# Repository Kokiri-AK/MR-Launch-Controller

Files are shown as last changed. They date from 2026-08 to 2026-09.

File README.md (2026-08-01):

# MR-Launch-Controller
Model Rocket Launch Controller Schematic

Original Schematic: Ryan Wilkus

Forked by Jonathan M

Circuit is originally based on a great paper from 2009 by J.R. Brohm discussing model rocket igniter continuity testing [Paper](https://www.rocketshoppe.com/info/Igniter_Continuity_Tests.pdf). 

The paper proposed using a transistor circuit to decrease the continuity check current of the igniter. This circuit is an expanded realization of that suggestion.

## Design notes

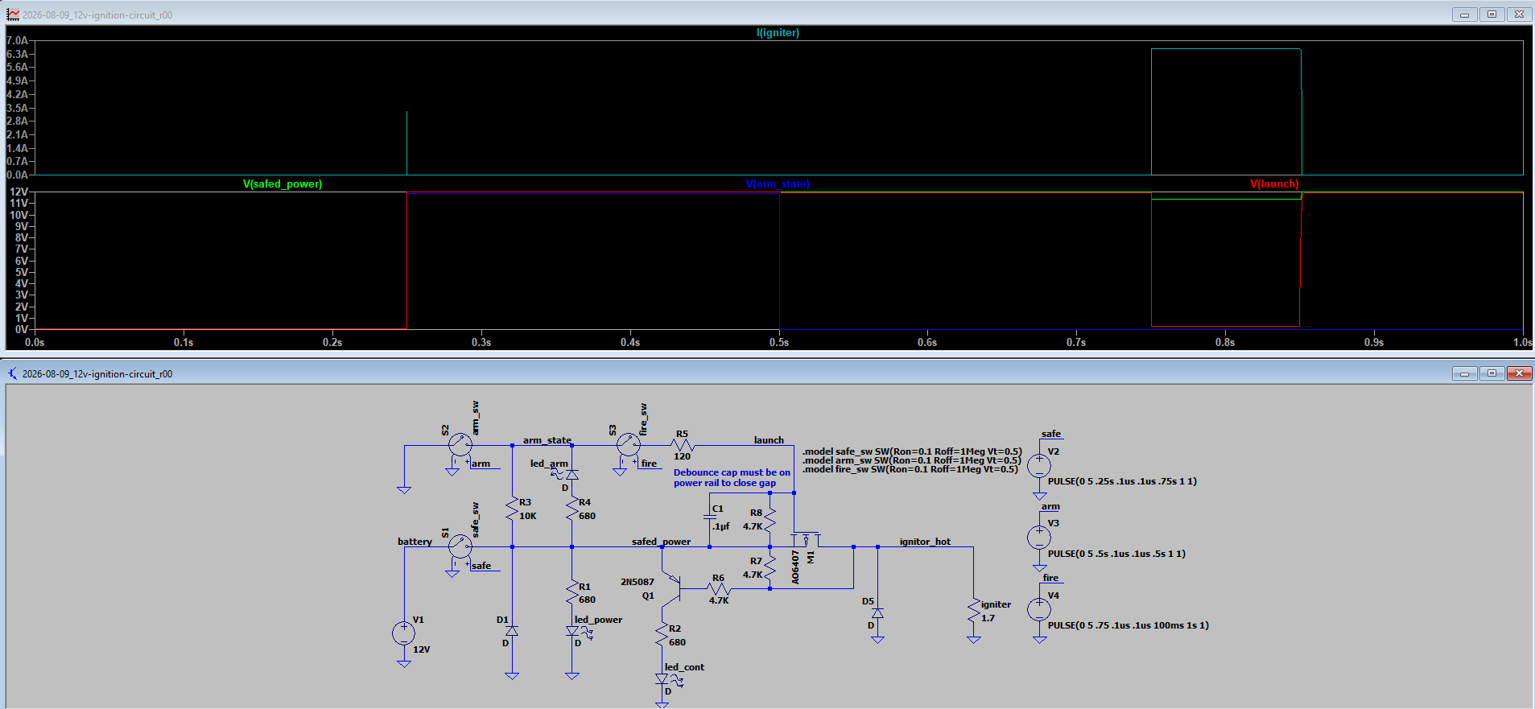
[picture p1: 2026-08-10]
5_Photos/12v_simulation.png

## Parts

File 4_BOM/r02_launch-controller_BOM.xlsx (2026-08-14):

Index | Manufacturer Part Number | Manufacturer Name | Description | Attrition % | Requested Quantity 1 | Pack Quantity 1 | Pack Type 1 | Digi-Key Part Number 1 | Unit Price 1 | Extended Price 1 | Minimum Order Quantity 1 | Customer Reference | Reference Designator | Part Status | RoHS Status | Original Part numbers
1 | 1729128 | Phoenix Contact | TERM BLK 2P SIDE ENT 5.08MM PCB |  | 1 | 1 | Bulk | 277-1247-ND | 0.95 | 0.95 | 1 | J1 |  | Active | ROHS3 Compliant | 1729128
2 | D6R40 F2 LFS | C&K | SWITCH PUSH SPST-NO 0.1A 32V |  | 1 | 1 | Tray | 401-1992-ND | 1.08000 | $1.08 | 1 | SW2 |  | Active | ROHS3 Compliant | 401-1992-ND
3 | BU-34 | Mueller Electric Co | GATOR CLIP STEEL NON-INSUL 5A |  | 2 | 2 | Bulk | 314-1017-ND | 0.54000 | $1.08 | 1 |  |  | Active | RoHS Compliant | 314-1017-ND
4 | C566D-RFE-CV0X0BB1 | CreeLED, Inc. | LED RED DIFFUSED 5MM OVAL T/H |  | 1 | 1 | Bulk | C566D-RFE-CV0X0BB1-ND | 0.18000 | $0.18 | 1 | D5 |  | Active | RoHS Compliant | C566D-RFE-CV0X0BB1-ND
5 | C5SMF-GJE-CX14Q7T2 | CreeLED, Inc. | LED GREEN CLEAR 5MM OVAL T/H |  | 1 | 1 | Cut Tape (CT) | C5SMF-GJE-CX14Q7T2CT-ND | 0.30000 | $0.30 | 1 | D3, D4 |  | Active | RoHS Compliant | C5SMF-GJE-CX14Q7T2CT-ND
7 | 2N3906 | Diotec Semiconductor | TRANS PNP 40V 0.2A TO-92 |  | 1 | 1 | Bulk | 4878-2N3906CT-ND | 0.77000 | 0.14 | 1 | Q1 |  | Active | ROHS3 Compliant | 4878-2N3906CT-ND
8 | ANT11SF1CQE | CIT Relay and Switch | SWITCH TOGGLE SPDT 5A 120V |  | 1 | 1 | Bulk | 2449-ANT11SF1CQE-ND | 1.26000 | $1.26 | 1 | SW1 |  | Active | RoHS Compliant | 2449-ANT11SF1CQE-ND
9 | P6KE18A | YAGEO | TVS DIODE 15.3VWM 25.2V DO204AC |  | 2 | 2 | Box | P6KE18ALFCT-ND | 0.38000 | $0.76 | 1 | D1, D2 |  | Active | ROHS3 Compliant | P6KE18ALFCT-ND
10 | 0ZRS1000FF1A | Bel Fuse Inc. | PTC RESET FUSE 32V 10A RADIAL |  | 1 | 1 | Cut Tape (CT) | 5923-0ZRS1000FF1A-ND | 2.24 | 2.24 | 1 | PTC1 |  | Active | ROHS3 Compliant | 5923-0ZRS1000FF1A-ND
11 | CF14JT300R | Stackpole Electronics Inc | RES 300 OHM 5% 1/4W AXIAL |  | 3 | 3 | Cut Tape (CT) | CF14JT300RCT-ND | 0.10000 | $0.30 | 1 | R1, R4, R7 |  | Active | ROHS3 Compliant | CF14JT300RCT-ND
12 | CF14JT4K70 | Stackpole Electronics Inc | RES 4.7K OHM 5% 1/4W AXIAL |  | 3 | 3 | Cut Tape (CT) | CF14JT4K70CT-ND | 0.10000 | $0.30 | 1 | R2, R3, R6 |  | Active | ROHS3 Compliant | CF14JT4K70CT-ND
13 | AOD413A | Alpha & Omega Semiconductor Inc. | MOSFET P-CH 40V 12A TO252 |  | 1 | 1 | Cut Tape (CT) | 785-1218-1-ND | 1.12 | 1.12 | 1 | Q2 |  | Active |  | AOD413A
14 | CC0603ZRY5V9BB104 | YAGEO | CAP CER 0.1UF 50V Y5V 0603 |  | 1 | 1 | Cut Tape (CT) | 311-1343-1-ND | 0.1 | 0.1 | 1 | C1 |  | Active |  | CC0603ZRY5V9BB104
15 | CF14JT10K0 | Stackpole Electronics Inc | RES 10K OHM 5% 1/4W AXIAL |  | 1 | 1 | Cut Tape (CT) | CF14JT10K0TR-ND | 0.1 | 0.1 | 1 | R8 |  | Active |  | CF14JT10K0
16 | CF14JT62R0 | Stackpole Electronics Inc | RES 62 OHM 5% 1/4W AXIAL |  | 1 | 1 | Cut Tape (CT) | CF14JT62R0CT-ND | 0.1 | 0.1 | 1 | R9 |  | Active |  | CF14JT62R0

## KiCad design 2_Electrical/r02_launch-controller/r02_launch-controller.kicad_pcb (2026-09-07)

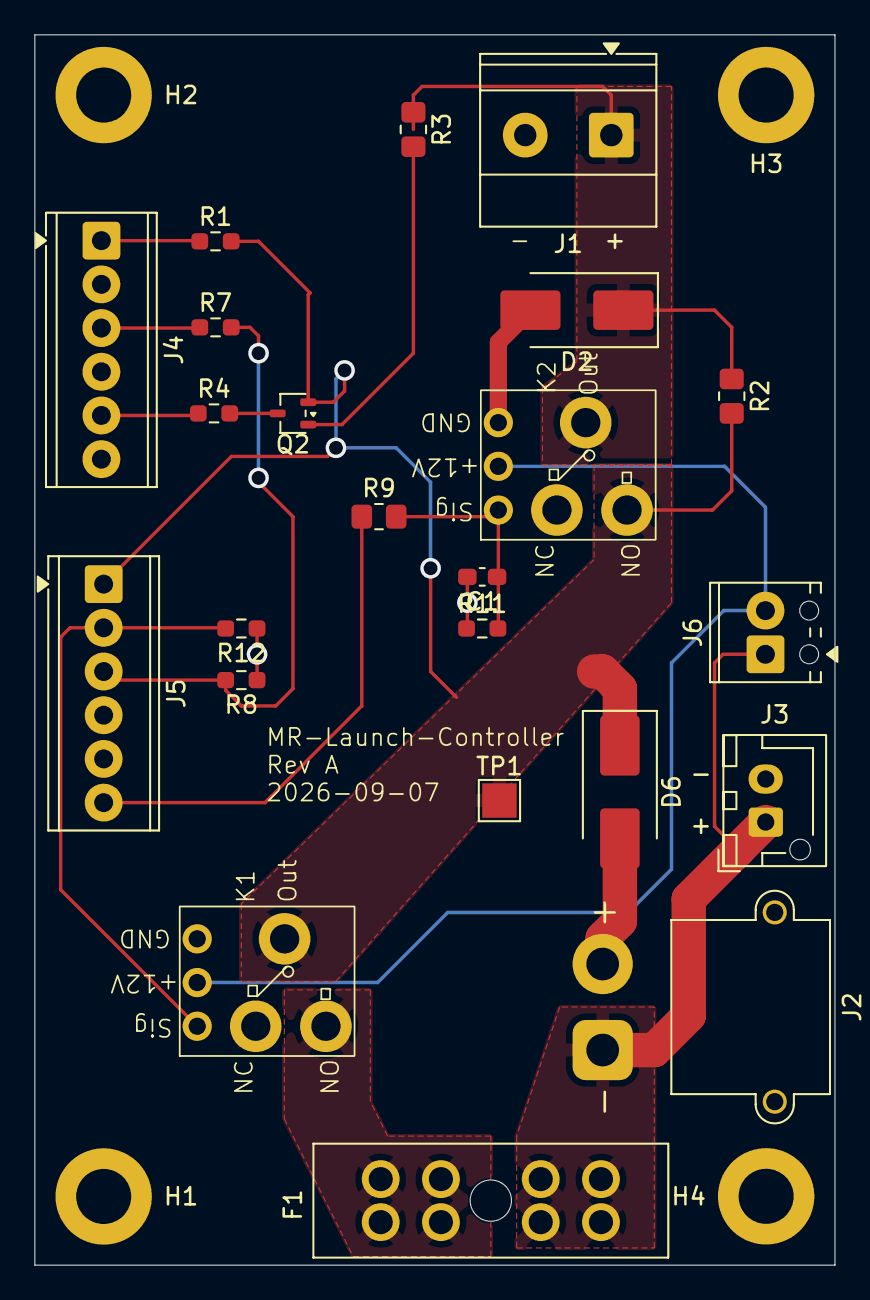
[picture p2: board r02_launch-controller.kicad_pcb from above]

Board: 2 copper layers, 46.5 x 71.5 mm, 27 parts (0 on the bottom side), 15 nets.

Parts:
C1: .1uf; C_0603_1608Metric_Pad1.08x0.95mm_HandSolder
D2, D6: SM6T18A; D_SMB_Handsoldering
F1: 178.6165.0001; FuseHolder_Blade_ATO_Littelfuse_FLR_178.6165
H1, H2, H3, H4: MountingHole; MountingHole_3.2mm_M3_DIN965_Pad
J1: 1729128; TerminalBlock_Phoenix_MKDS-1,5-2_1x02_P5.00mm_Horizontal
J2: XT30PW-M; AMASS_XT30PW-M_1x02_P2.50mm_Horizontal
J3: B2B-XH-AM; JST_XH_B2B-XH-AM_1x02_P2.50mm_Vertical
J4, J5: 1725698; TerminalBlock_Phoenix_MPT-0,5-6-2.54_1x06_P2.54mm_Horizontal
J6: Screw_Terminal_01x02; TerminalBlock_Phoenix_MPT-0,5-2-2.54_1x02_P2.54mm_Horizontal
K1, K2: 12V-relay
Q2: BC807W; SOT-323_SC-70
R1, R4, R7: 300; R_0603_1608Metric_Pad0.98x0.95mm_HandSolder
R2, R3: 4.7K; R_0805_2012Metric_Pad1.20x1.40mm_HandSolder
R8, R11, R12: 10K; R_0603_1608Metric_Pad0.98x0.95mm_HandSolder
R9: 60; R_0805_2012Metric_Pad1.20x1.40mm_HandSolder
TP1: TestPoint; TestPoint_Pad_2.0x2.0mm

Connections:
+12V: J6.2, K1.2 (+12V), K2.2 (+12V)
/armed: J5.3, J5.4, J5.5, R7.2, R8.2
/armed_LED: J4.3, R7.1
/battery: F1.1, J2.1, J3.1, J6.1
/continuity_LED: J4.5, R4.1
/igniter_hot: D2.1, J1.1, K2.6 (OUT), R2.1, R3.1
/launch: J5.6, R9.1
/launch_sw: C1.1, K2.1 (Signal), R9.2, R11.2
/power_LED: J4.1, R1.1
/safe_relay: J5.2, K1.1 (Signal), R12.2
/safed_power: D6.1, J5.1, K1.6 (OUT), K2.4 (NO), Q2.2 (E), R1.2, R2.2, TP1.1 (1_1)
GND: C1.2, D2.2, D6.2, J1.2, J2.2, J3.2, J4.2, J4.4, J4.6, K1.3 (GND), K1.5 (NC), K2.3 (GND), K2.5 (NC), R8.1, R11.1, R12.1
unnamed: F1.2, K1.4 (NO)
unnamed: Q2.1 (B), R3.2
unnamed: Q2.3 (C), R4.2

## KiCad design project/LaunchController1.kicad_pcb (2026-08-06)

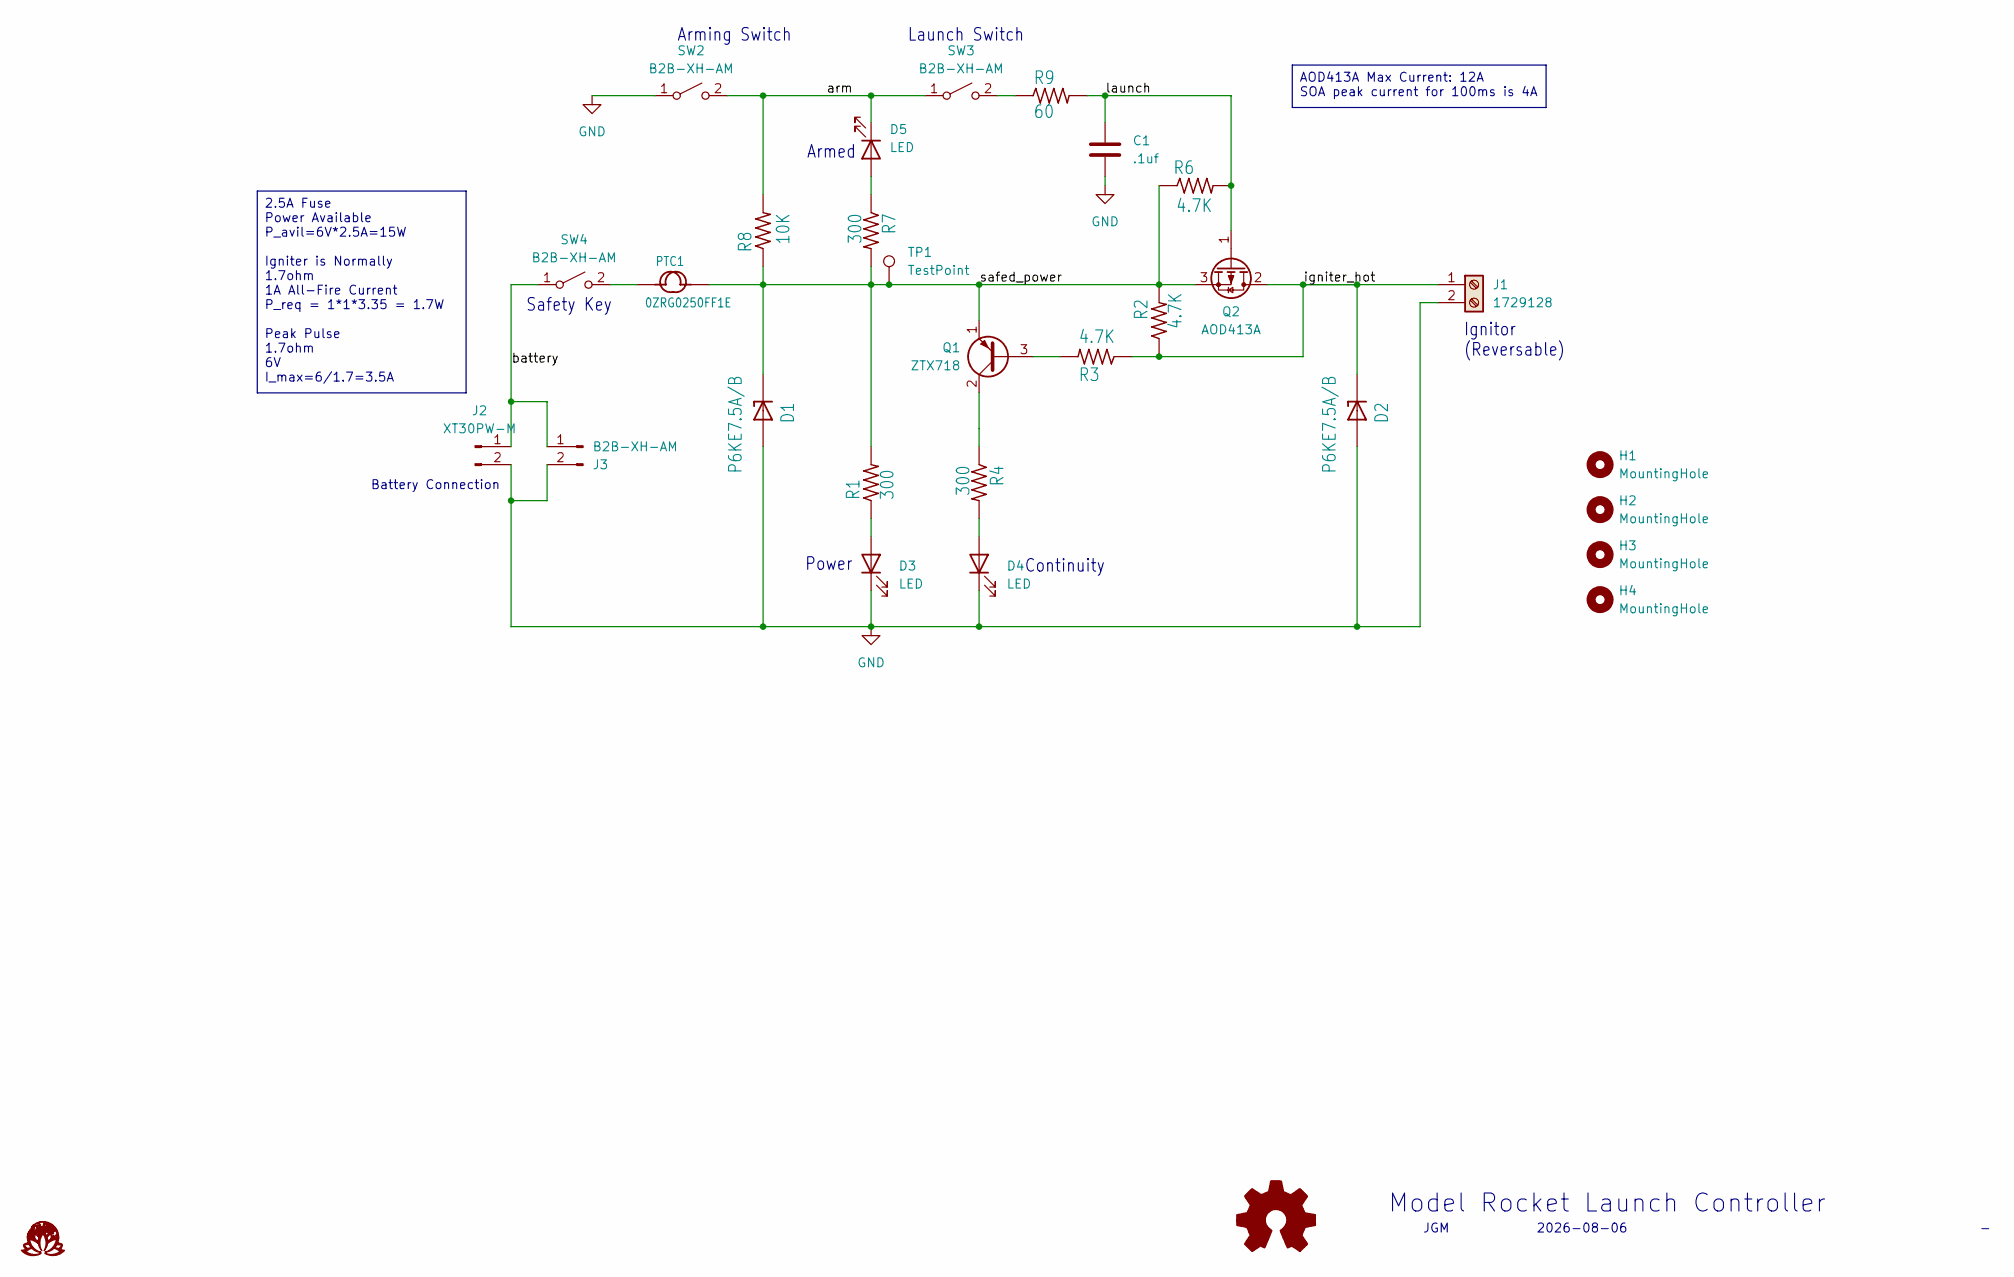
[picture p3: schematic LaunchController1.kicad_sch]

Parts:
C1: .1uf; C_0603_1608Metric_Pad1.08x0.95mm_HandSolder
D1, D2: P6KE7.5A/B; D_DO-15_P12.70mm_Horizontal
D3, D4, D5: LED; LED_D5.0mm
H1, H2, H3, H4: MountingHole; MountingHole_3.2mm_M3_DIN965_Pad
J1: 1729128; TerminalBlock_Phoenix_MKDS-1,5-2_1x02_P5.00mm_Horizontal
J2: XT30PW-M; AMASS_XT30PW-M_1x02_P2.50mm_Horizontal
J3: B2B-XH-AM; JST_XH_B2B-XH-AM_1x02_P2.50mm_Vertical
PTC1: 0ZRG0250FF1E; Fuse_BelFuse_0ZRE0012FF_L8.3mm_W3.8mm
Q1: ZTX718; TO-92_Inline
Q2: AOD413A; TO-252-3_TabPin2
R1, R4, R7: 300; R_Axial_DIN0309_L9.0mm_D3.2mm_P12.70mm_Horizontal
R2, R3, R6: 4.7K; R_Axial_DIN0309_L9.0mm_D3.2mm_P12.70mm_Horizontal
R8: 10K; R_Axial_DIN0309_L9.0mm_D3.2mm_P12.70mm_Horizontal
R9: 60; R_Axial_DIN0309_L9.0mm_D3.2mm_P12.70mm_Horizontal
SW2, SW3, SW4: B2B-XH-AM; JST_XH_B2B-XH-AM_1x02_P2.50mm_Vertical
TP1: TestPoint; TestPoint_Pad_2.0x2.0mm

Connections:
/arm: D5.1 (K), R8.2, SW2.2 (B), SW3.1 (A)
/battery: J2.1, J3.1, SW4.1 (A)
/igniter_hot: D2.1, J1.1, Q2.2 (D), R2.1, R3.1
/launch: C1.1, Q2.1 (G), R6.2, R9.2
/safed_power: D1.1, PTC1.2, Q1.1 (E), Q2.3 (S), R1.2, R2.2, R6.1, R7.2, R8.1, TP1.1 (1_1)
GND: C1.2, D1.2, D2.2, D3.1 (K), D4.1 (K), J1.2, J2.2, J3.2, SW2.1 (A)
unnamed: D3.2 (A), R1.1
unnamed: D4.2 (A), R4.2
unnamed: D5.2 (A), R7.1
unnamed: Q1.3 (B), R3.2
unnamed: Q1.2 (C), R4.1
unnamed: R9.1, SW3.2 (B)
unnamed: PTC1.1, SW4.2 (B)

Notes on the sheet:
Ignitor (Reversable)
Continuity
Battery Connection
Armed
Power
Arming Switch
JGM
${COMPANY}
${REVISION}
Model Rocket Launch Controller
Launch Switch
Safety Key
2026-08-06
2.5A Fuse Power Available P_avil=6V*2.5A=15W Igniter is Normally 1.7ohm 1A All-Fire Current P_req = 1*1*3.35 = 1.7W Peak Pulse 1.7ohm 6V I_max=6/1.7=3.5A
AOD413A Max Current: 12A SOA peak current for 100ms is 4A

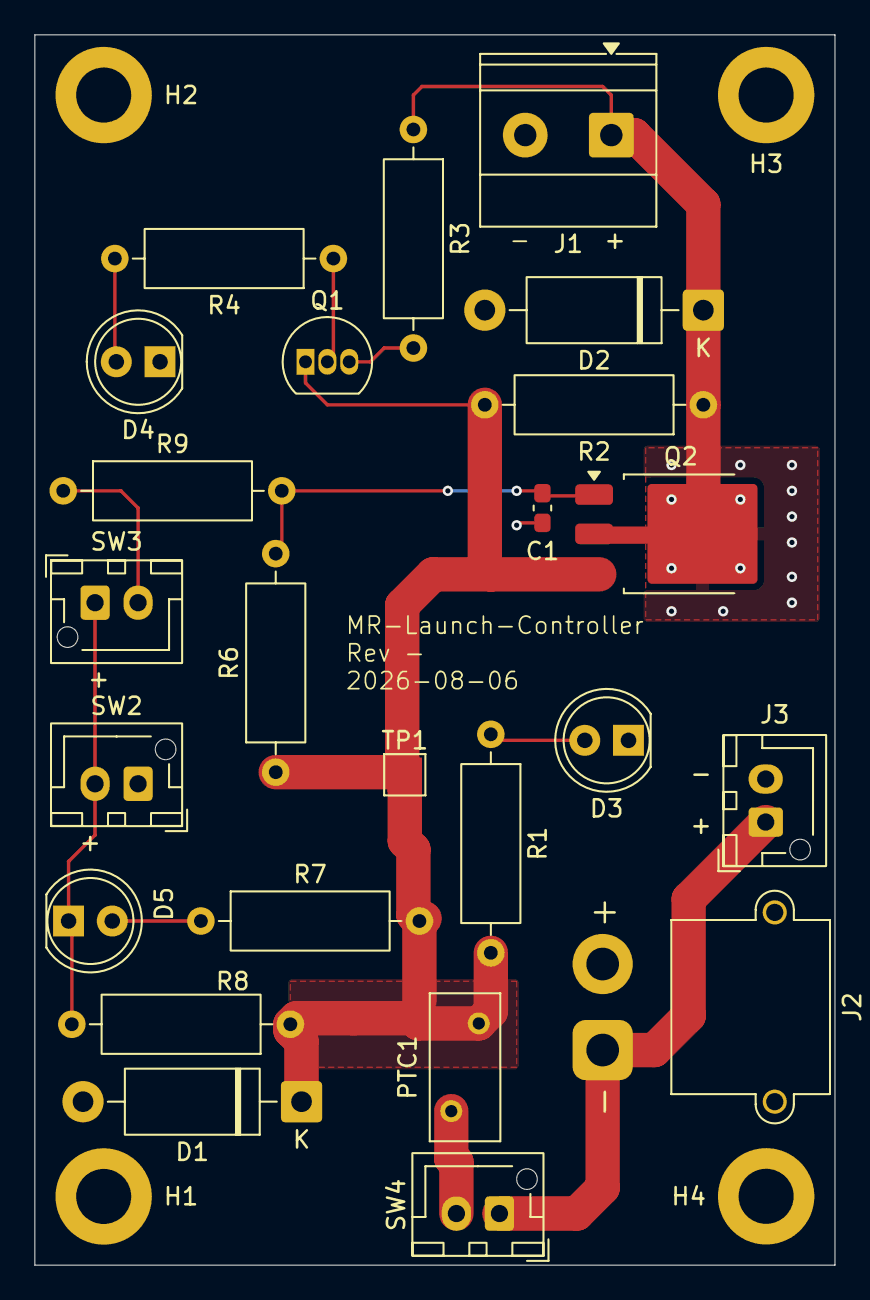
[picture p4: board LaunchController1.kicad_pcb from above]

Board: 2 copper layers, 46.5 x 71.5 mm, 28 parts (0 on the bottom side), 13 nets.

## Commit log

2026-07-31 Feat: Schematic updates, added a safety key and moved arming switch
    [LaunchController1.kicad_pcb, LaunchController1.kicad_sch]
2026-08-01 Feat: increased PTC current rating, dropped R5 to ensure saturation on Q2
    Also switched all parts (except the battery case) to a KiCad library part to update. Moving the design to KiCad (r.i.p Eagle).
    Increased current rating of PTC1 to 2.5A hold, 5A trip to reduce possibility of inadvertent tripping.
    Dropped R5 to ensure saturation on Q2
    Q2 is surprisingly able to handle the pulse current. Peak pulse is 6A, which should cover requirement. Maybe consider ZTX618 instead, which has a higher amp rating.
    Q2 (ZTX718) is being retired, so if you're reading this you need to pick a different part.
    [LaunchController1 BOM.xlsx, LaunchController1.kicad_pcb, LaunchController1.kicad_sch]
2026-08-01 Chore: Cleanup, Readme modification
    [Launch Controller 1 Rev A.stl, Launch Controller 1.skp, LaunchController1 BOM.xlsx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]
2026-08-01 Feat: Swapped Q2 from PNP BJT to PMOS
    Wasn't feeling great about how close the peak pulse requirement of the BJT was to the theoretical maximum current pulse. Also didn't like the current required to put BJT into saturation. Swapped for AOD413A PMOS. Also changed resistors to accommodate PMOS gate drive.
    Schematic is done, need to lay out.
    [LaunchController1 BOM.xlsx, LaunchController1.kicad_sch, MR-Launch-Controller_BOM.xlsx]
2026-08-02 Add Apache and CERN licenses; remove KiCad lock
    Add LICENSE (Apache License 2.0) and LICENSE_CERN (CERN-OHL-P) to explicitly provide permissive licensing for software and hardware designs.
2026-08-06 layout: Updated layout for schematic
    Rev -
    [LaunchController1.kicad_pcb, LaunchController1.kicad_sch]
2026-08-10 simulation: Added spice simulation for 6v and 12v versions
    Whoops, should not have placed debounce cap on the ground. Switched it to hot rail and got rid of a sneak circuit possibility.
    [12V_MR-Launch-Controller_BOM.xlsx, 6V_MR-Launch-Controller_BOM.xlsx, MR-Launch-Controller_BOM.xlsx]
2026-08-14 simulation: created simulation for 12V igntion
    Having problems with bleed through on the FET during startup. It's small, but not ideal for a pyrotechnic initiator. May abandon this design.
    [12V_MR-Launch-Controller_BOM.xlsx]
2026-08-30 schematic: changed circuit to relays
    Changed the circuit to use 12 relays instead of solid state. Simulations showed that solid state leaked current during turn on, and I wanted more isolation than that. Relays will do what I want in a slightly more chunky form factor.
    [r02_launch-controller.kicad_pcb, r02_launch-controller.kicad_sch, r02_launch-controller_BOM.xlsx]
2026-09-07 layout: Laid out Rev A
    Should be ready for a prototype. Same form factor as before, but all surface mount now.
    [r02_launch-controller.kicad_pcb, r02_launch-controller.kicad_sch]
